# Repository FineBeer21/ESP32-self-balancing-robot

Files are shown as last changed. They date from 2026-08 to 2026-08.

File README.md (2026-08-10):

# ESP32-self-balancing-robot
A self-balancing, two-wheeled robot built from scratch using an ESP32 microcontroller, an MPU6050 IMU, and NEMA stepper motors. Using VS code with platformio

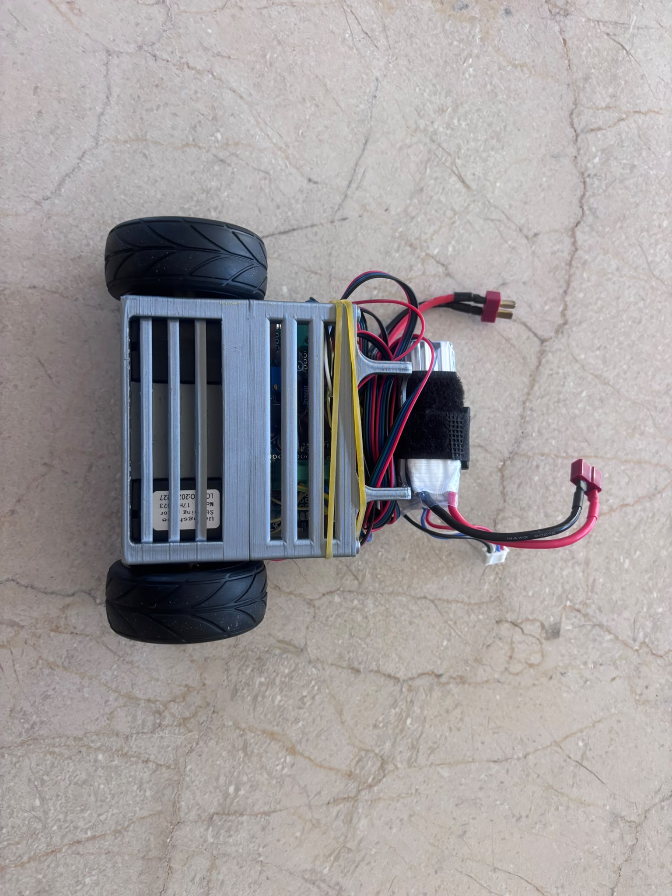
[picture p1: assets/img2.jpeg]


---

## System Overview

* **Microcontroller:** ESP32
* **IMU:** MPU6050
* **Actuators:** NEMA 17 Stepper Motors
* **Drivers:** A4988 Stepper Motor Drivers
* **Power:** 12V LiPo Battery with a Buck Converter stepping down to 5V

---

## Mechanical Design & 3D Printing

The chassis was designed from scratch using **Fusion 360**. Key design considerations include:

* **Thermal Management:** Cutouts and ventilation paths were integrated into the motor mounts to cool down the steppers.
* **Material Selection:** 
  * **Base Level:** Strongly recommended to print in **PETG** due to thermal output from the stepper motors. *(Printed in PLA for this build due to material availability, but PETG is advised).*
  * **Upper Levels:** Printed in **PLA** for flexibility and lower weight.

---

## Hardware & Assembly

* **Assembly Method:** Point-to-point hand soldering on perfboard.
* **Note for Builders:** Hand wiring in a tight self-balancing chassis increases noise and risk of loose connections. **Designing a custom PCB is strongly recommended**.

---

## Software & Engineering Challenges

### 1. Inverted IMU & Acceleration Glitches
* **Problem:** The robot reacted erratically with severe lag. Debugging sensor outputs revealed that pitch readings were corrupting under high acceleration due to the MPU6050 being physically mounted inverted.
* **Solution:** Constrained by the mechanical layout, I implemented a **custom Complementary Filter** and manually negating the gyroscope axis sign to restore accurate pitch tracking.

### 2. Custom Timer ISR vs. Stepper Library
* **Initial Approach:** Wrote a bare-metal timer Interrupt Service Routine (ISR) to drive step pulses directly.
* **Trade-off:** While functional and making the motor's data easily trackable, the raw ISR lacked smooth acceleration profiles required to prevent motor stall. 
* **Current State:** Migrated to an established stepper library for dynamic step timing. The original custom ISR code is retained in the repository (`custom_isr_driver/self_prot.cpp`) for reference.

### 3. Mechanical Vibrations & LPF Latency Trade-off
Stepper motor steps generate high-frequency mechanical noise that propagates into the MPU6050, introducing jitter into pitch calculations.

* **Filter Experimentation:** Implemented a software Low-Pass Filter (LPF) to dampen sensor noise.
* **The Trade-off (Phase Lag):** While the LPF slightly softened raw signal spikes, it introduced phase delay (latency) into the feedback loop. For a fast-responding self-balancing system, this delay reduced PID responsiveness and compromised recovery time.
* **Takeaway:** Digital filtering alone proved insufficient due to the latency constraint. Future iterations require hardware-level fixes, maybe vibration dampeners under the IMU or transitioning to a rigid custom PCB.

Without LPF:

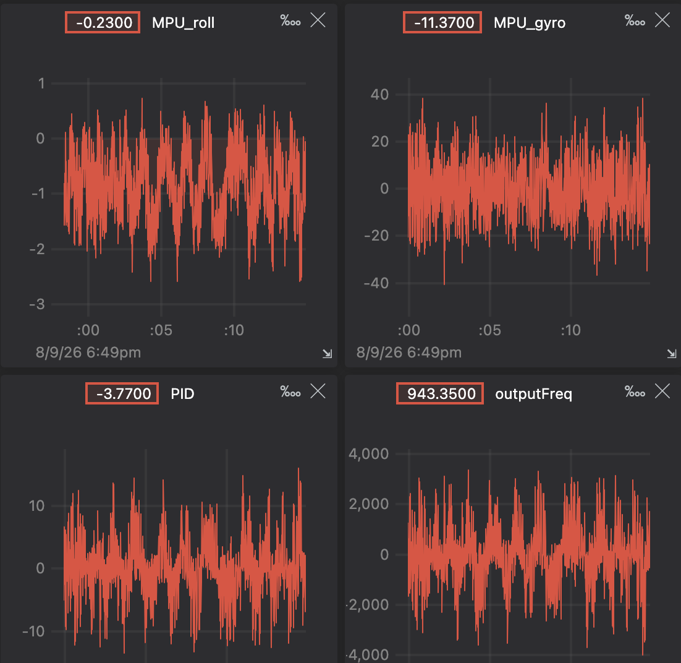
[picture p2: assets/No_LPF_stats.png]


With LPF:

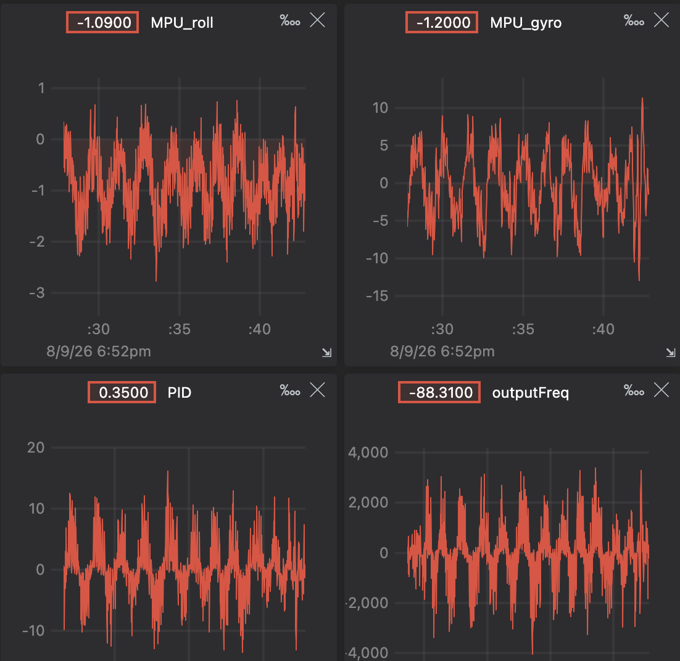
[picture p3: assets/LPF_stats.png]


---

## Video

Check out the robot in action:

<p align="center">
  Robot Demo GIF
</p>

---

## Future Roadmap

- [ ] **Remote Control Integration:** Implement wireless control via Wi-Fi (ESP-NOW) or Bluetooth.
- [ ] **Directional Movement:** Translate target tilt angles to move forward/backward.
- [ ] **Yaw Control:** Implement differential motor driving for steering capabilities.

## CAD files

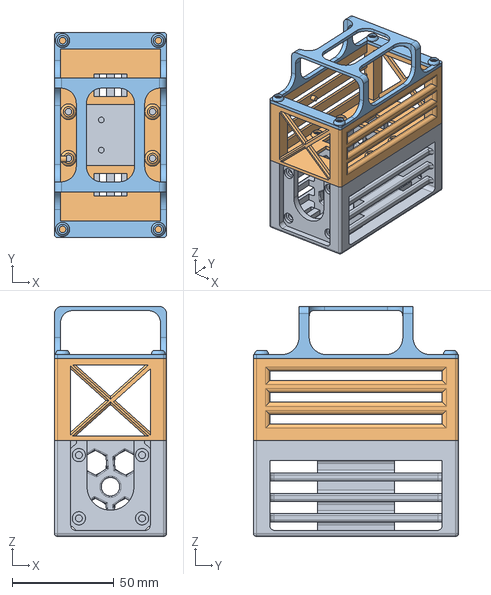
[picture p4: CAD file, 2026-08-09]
cad_models/full_assembly.step
55.0 x 100.6 x 112.8 mm

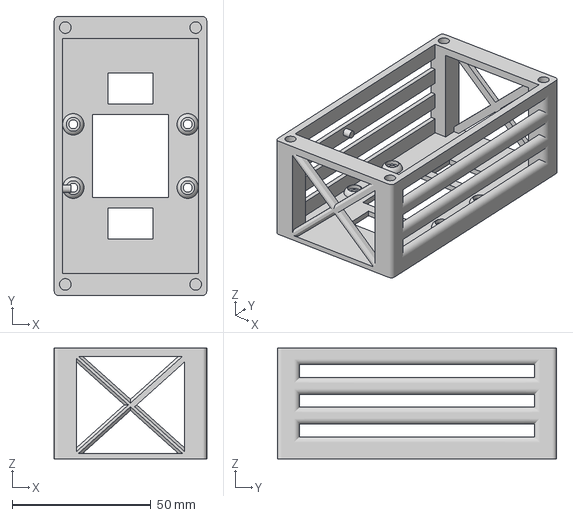
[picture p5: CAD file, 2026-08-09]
cad_models/main_electronics_deck.3mf
55.0 x 100.6 x 40.0 mm

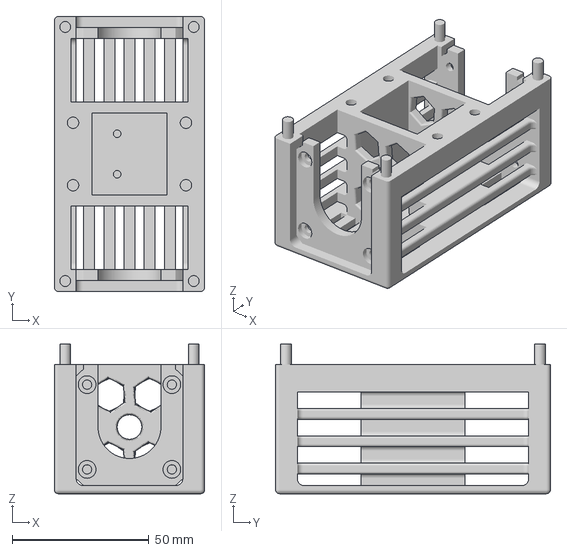
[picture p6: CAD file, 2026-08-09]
cad_models/motor_mount_base.3mf
55.0 x 100.6 x 54.7 mm

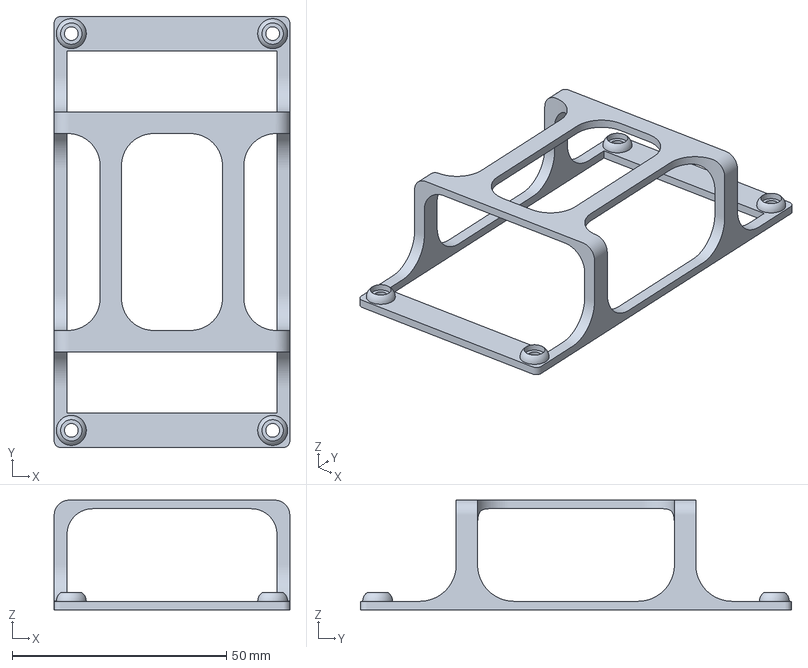
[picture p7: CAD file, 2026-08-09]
cad_models/top_plate.3mf
55.0 x 100.6 x 25.6 mm

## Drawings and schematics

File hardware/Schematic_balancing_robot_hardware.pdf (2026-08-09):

A | A

1

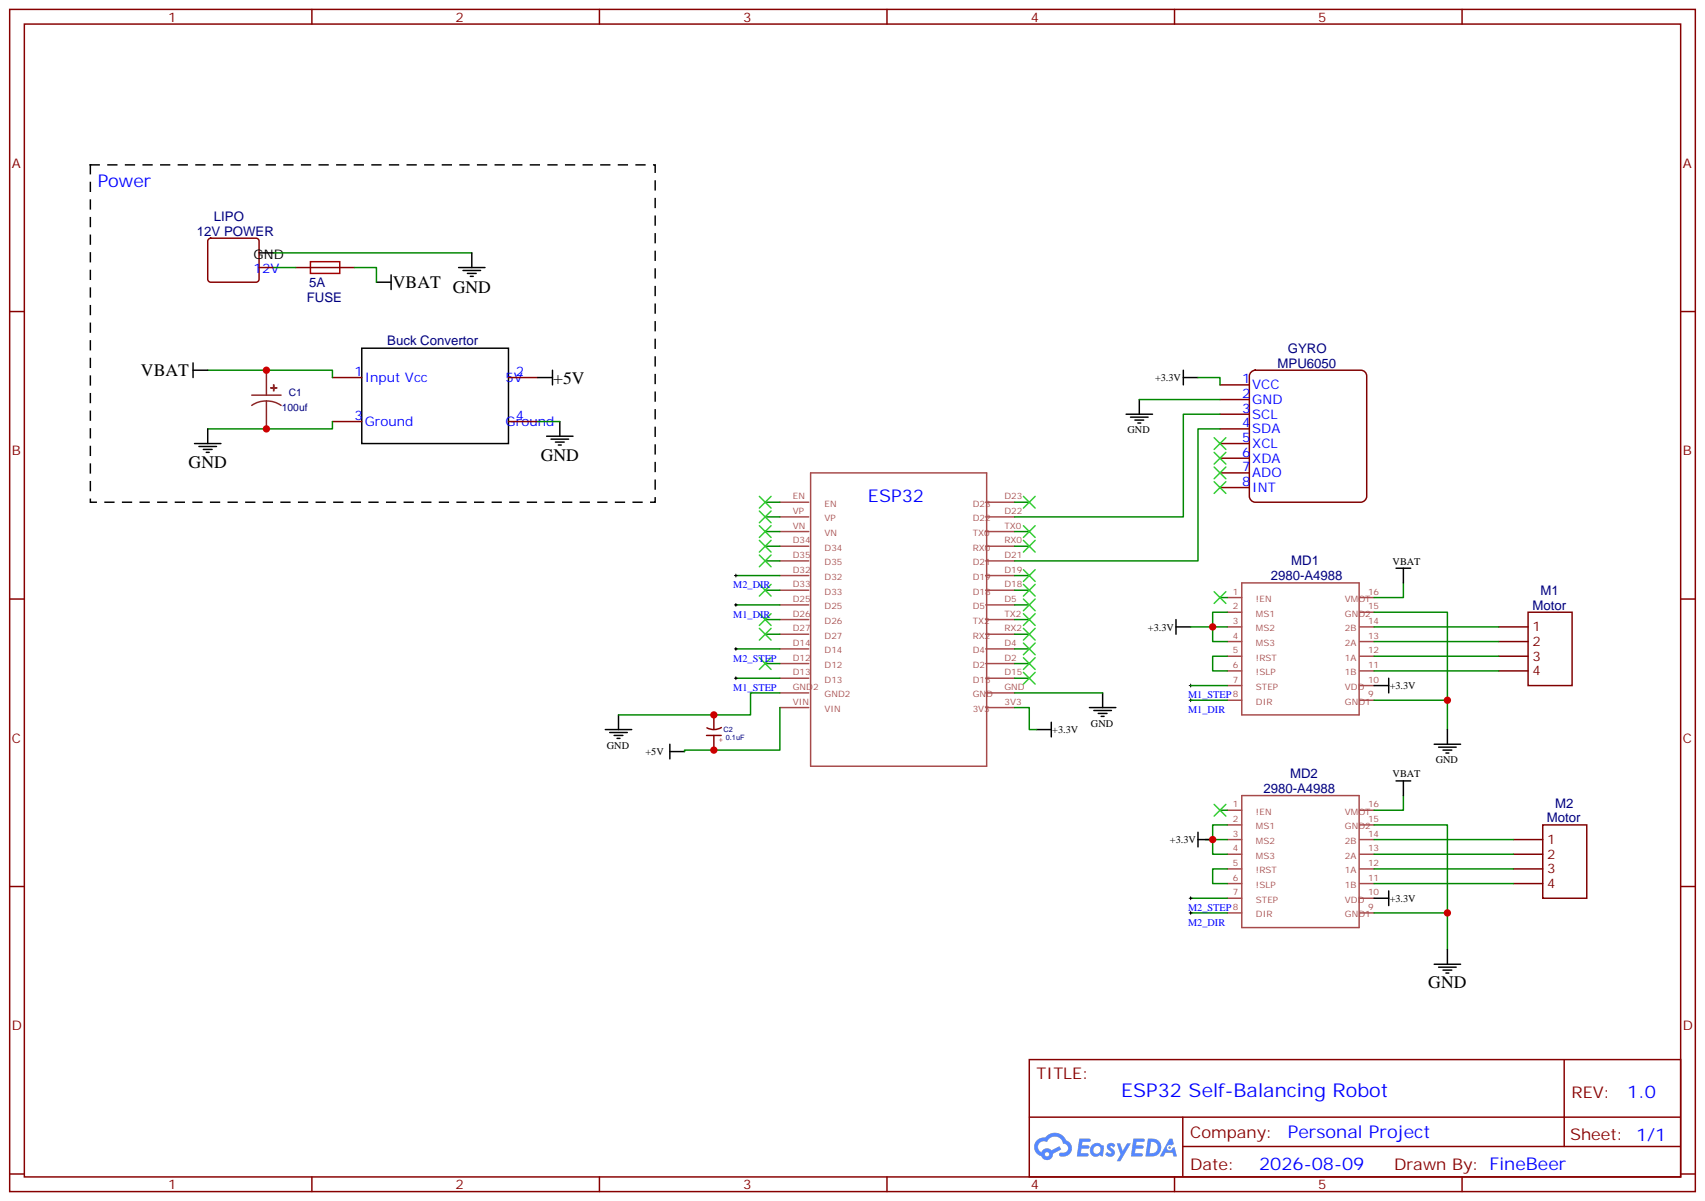
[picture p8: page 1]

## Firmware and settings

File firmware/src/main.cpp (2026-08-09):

#include <Arduino.h>
#include <Wire.h>
#include <MPU6050_light.h>
#include <FastAccelStepper.h>

//def pins
const int DIR_PIN1 = 25;
const int DIR_PIN2 = 32;
const int STEP_PIN1 = 13;
const int STEP_PIN2 = 14;

// Engine vars
FastAccelStepperEngine engine = FastAccelStepperEngine();
FastAccelStepper *leftMotor = NULL;
FastAccelStepper *rightMotor = NULL;

int motorAcceleration = 15000; // You can change this value to adjust the acceleration of the motors

MPU6050 mpu(Wire);

// Freq timers
float dt = 0.005;
float sTimer = dt * 1000000.0f; // 5000 micro seconds = 200 HZ
unsigned long lastMeasured = 0;

float printTimer = 20000.0f;

// PID coefficient
float Kp = 7.0f;
float Ki = 0.2f;
float Kd = 0.1f;

float lastError = 0.0f;
float lastDer = 0.0f;

float lpFilter = 0.05f;
float integralSum = 0.0f;

int maxFreq = 12000;

float angleOffset = -0.85f; // Usefull if center of gravity is not 0.0 or when wanting to move forward/backward

float normalizedFreq = 250.0f;

// For control - using teleplot extention
struct teleplotData
{
    float currentAngle = 0.0f;
    float currentGyro = 0.0f;
    float currentPID = 0.0f;
    float outputFreq = 0.0f;
    u_int32_t stepsCount = 0;
};

teleplotData teleDa;

// PID function
float PID (float setPoint, float currentRoll, float &lastError, float &integralSum, float gyroRate, float dt = 0.005f)
{
    float error = (setPoint - currentRoll); 
    if(fabs(error) < 1.0f) error *= fabs(error);
        
    integralSum = (integralSum + error * dt) * 0.999f;
    lastDer = lpFilter * gyroRate + (1.0f - lpFilter) * lastDer;
    teleDa.currentGyro = lastDer; // Updating for teleplot

    float rawPID =  (Kp * error) + (Ki * integralSum) + (Kd * lastDer);
    return rawPID;
}

// Motor control function
void fastAccMotor(float calculatedPID, FastAccelStepper *motor){
    float outputFreq = calculatedPID * normalizedFreq;
    static bool movingForward; // making sure we don't call runForward() or runBackward() multiple times in a row, if you want to add rotation theres need to be one for each motor

    teleDa.outputFreq = outputFreq; // Updating for teleplot
    
    uint32_t absFreq = (uint32_t)abs(outputFreq); 

    if(absFreq > maxFreq) absFreq = maxFreq;
    if (absFreq < 20) { 
    motor->setSpeedInHz(0); // stop the motor if the frequency is too low
    motor->stopMove();
    } else {
        motor->setSpeedInHz(absFreq);

        bool shouldMoveForward = (outputFreq > 0);

        if (shouldMoveForward && !movingForward) {
        motor->runForward();
        movingForward = true;
        } else if(!shouldMoveForward && movingForward) {
        motor->runBackward();
        movingForward = false;
        }   
    }
}


void setup() {
    Serial.begin(921600); // reccommended to use 921600 for teleplot
    Wire.begin(); 
    Wire.setTimeOut(10); // I2C timout in ms

    byte status = mpu.begin();
    Serial.print(F("loading mpu... Status is: "));
    Serial.println(status);

    while (status!=0) {}

    Serial.println(F("MPU ON, calc offset"));

    // Set offsets for MPU6050, these values should be calibrated for your specific MPU6050 module
    mpu.setAccOffsets(-0.01f, 0.07f, -2.06f);
    mpu.setGyroOffsets(-1.98f, 0.41f, -0.32f);

    // Engine setup
    engine.init();

    leftMotor = engine.stepperConnectToPin(STEP_PIN1);
  if (leftMotor) {
    leftMotor->setDirectionPin(DIR_PIN1);
    leftMotor->setAcceleration(motorAcceleration);
  }

  rightMotor = engine.stepperConnectToPin(STEP_PIN2);
  if (rightMotor) {
    rightMotor->setDirectionPin(DIR_PIN2);
    rightMotor->setAcceleration(motorAcceleration);
  }
}

void loop(){
    unsigned long currentMicro = micros();

    if(currentMicro - lastMeasured >= sTimer){
        float dty = (currentMicro - lastMeasured) / 1000000.0f;

        mpu.update();

        float accAngle = mpu.getAccAngleY();
        float gyroRate = -mpu.getGyroY();

        // Complementary filter to combine accelerometer and gyroscope data, I have inverted the gyroRate because the MPU6050 is mounted upside down on my robot, so the gyro readings are inverted
        static float filteredAngle = 0.0f;
        filteredAngle = 0.98f * (filteredAngle + gyroRate * dty) + 0.02f * accAngle; 

        float calculatedPID = PID(angleOffset, filteredAngle, lastError, integralSum, -gyroRate, dty);

        // Update teleplot data
        teleDa.currentAngle = filteredAngle;
        teleDa.currentPID = calculatedPID;

        // Update motors
        fastAccMotor(calculatedPID, leftMotor);
        fastAccMotor(-calculatedPID, rightMotor);

        lastMeasured = currentMicro;
    }

    // Teleplot data output
    static long lastPrinted = 0;
    if(currentMicro - lastPrinted > printTimer){
        lastPrinted = currentMicro;

        Serial.printf(">MPU_roll:%.2f\n", teleDa.currentAngle);
        Serial.printf(">MPU_gyro:%.2f\n", teleDa.currentGyro);
        Serial.printf(">PID:%.2f\n", teleDa.currentPID);
        Serial.printf(">outputFreq:%.2f\n", teleDa.outputFreq);
    }
}

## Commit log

2026-08-09 Enhance README with comprehensive project details
    Expanded the README with detailed sections on system overview, mechanical design, hardware assembly, software challenges, video demonstration, and future roadmap.
2026-08-09 Update material selection notes in README
    Removed note about detailed slicing settings and print instructions.
2026-08-10 Remove sensor noise comparison table from README
    Removed the table comparing raw sensor noise with filtered output from the README.
